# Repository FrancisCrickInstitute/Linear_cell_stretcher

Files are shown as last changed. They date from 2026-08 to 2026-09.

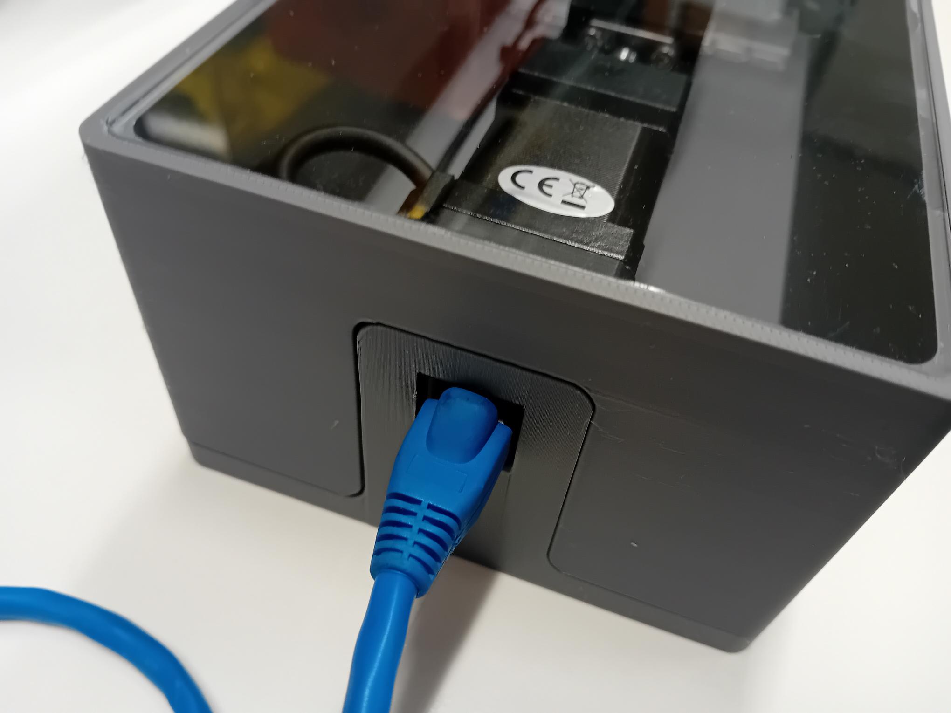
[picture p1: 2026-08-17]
Media/20260624_161759.jpg

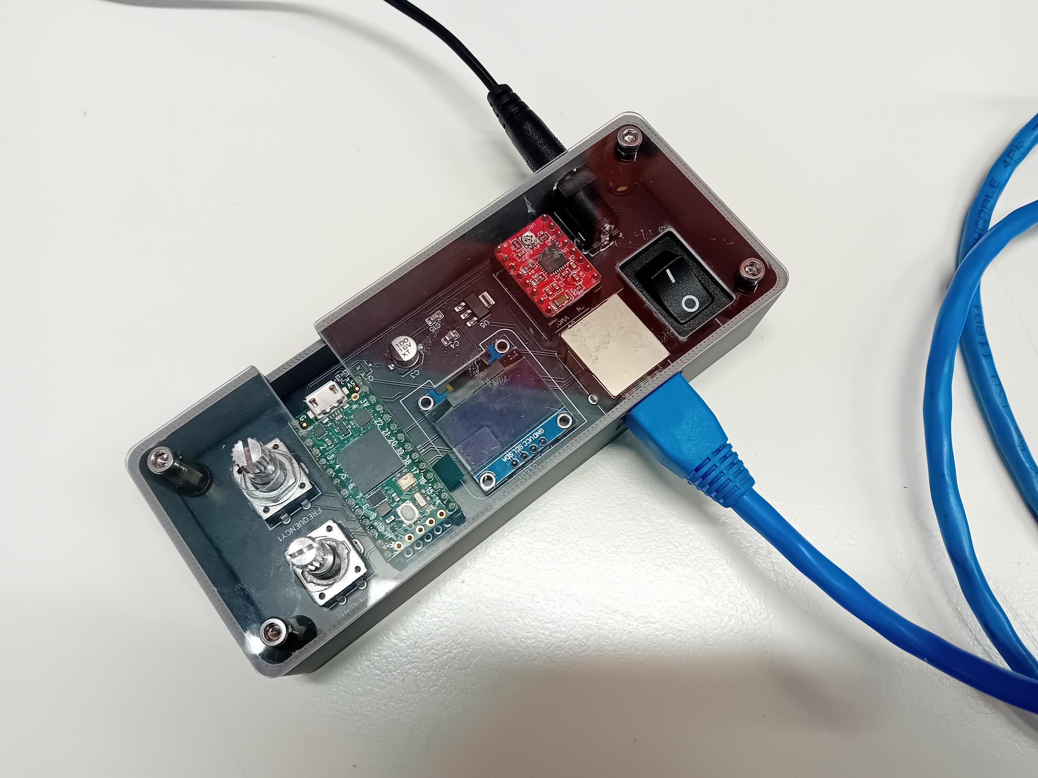
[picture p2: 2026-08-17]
Media/20260624_161749.jpg

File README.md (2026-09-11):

## Linear cell stretcher

Slide2

### Bill of Materials (BOM)

| Name | Quantity | Link |
| :--- | :---: | :--- |
| Linear stepper motor stage | 1 | [Stepper online](https://www.stepperonline.co.uk/nema-14-stepper-ball-screw-linear-actuator-1-5a-stroke-40mm-0-2nm-28-32oz-in-lead-2mm-0-0787-with-sensor-lmd14s18bab15-040.html) |
| Teensy 4.0 | 1 | [PiHut](https://thepihut.com/products/teensy-4-0-headers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) |
| Stepper motor driver | 1 | [Amazon](https://www.amazon.co.uk/dp/B07XRF8YPX?ref=fed_asin_title) |
| M2 threaded inserts | 4 | [Amazon](https://www.amazon.co.uk/dp/B0DFBVLHH7?ref=fed_asin_title&th=1) |
| M3 threaded inserts | 4 | [Amazon](https://www.amazon.co.uk/dp/B0DFBTB5LN?ref=fed_asin_title&th=1) |
| 5 mm rods (For the stretcher)| 1 | [Amazon](https://www.amazon.co.uk/dp/B0FHK1SYZM?ref=fed_asin_title&th=1) |
| 5.2 mm rods (For the mould)| 1 | [Amazon](https://www.amazon.co.uk/dp/B0DYT6DDYS?ref=fed_asin_title&th=1) |
| 12V AD/DC power adapter | 1 | [Amazon](https://www.amazon.co.uk/Adapter-100-240V-Transformer-Charger-Cameras/dp/B0FJ5NYKD2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) |
| M3 x 50 mm button screws | 2 | [Accu](https://www.accu.co.uk/socket-button-screws/8115-SSB-M3-50-A2) |
| RJ45 patch cable | 1 | [Amazon]() |
| M2 screws | 4 | [Accu]() |
| M3 screws | 10 | [Accu]() |

### Assembly instructions

- 3D print the components using more than 50% infill settings and PLA as material
- Laser cut the two-part lid cover
- Insert M2 threaded inserts on the bottom sides of the 3D printed parts: puller and the enclosure base
- Solder the Control PCB components

- Cut to the right length and solder the optical homing sensor cable and the stepper motor cable with the linear stepper connection board


- Attach the linear stepper connection board at the back of the motor with the 3D printed spacer in between removing two of the original stepper motor screws and replacing them by two 50 mm M3 screws.


- Place four M3 inserts in the enclosure base and lid holes
- Glue the big part of the lid cover on top of the 3D printed enclosure lid. The front smaller lid is not glued as it is removable to be able to access the wells with the pipette

- Change the position of the homing sensor using the front side M3 tapped holes


- Attach the 3D printed beam breaker on the carriage using two M3 screws


- Attach the 3D printed puller on top of the linear stage carriage using 4 M3 screws


- Attach the linear stage with the enclosure base (3D printed) using four M3 screws


- The 5 mm bars are held using 2 M2 screws in both the puller and the 3D printed enclosure


- Grab the optical sensor cable through the two cable guides


- Place 4 grub screws into the enclosure lid holes and place the lid on top of the enclosure base


- Upload the firmware on the Teensy 4

- Conenct the device and the control board using a RJ45 cable

- Connect the 12V, 36W power supply in the control board barrel jack connector


- Select the frequency (0.05 - 1 Hz) and stretch length (using the stretch and frequancy knobs) and mode (pressing the stretch knob) 

- Press the frequency knob to change the state of the device to active and it will start pulling, if pressed and held again it will stop at the end of the cycle

- Place the PDMS wells in the rods


#### Modes:
- Cyclic stretch
- Cyclic stretch holding for a defined period of time (specified in the firmware)
- Stretch and hold

### PDMS mould casting process

The moulds for creating the wells have been 3D printed using Formlabs clear V5 resin in a Form 4 3D printer. After IPA washing (15 min) and UV curing (60 degC for 1h on the Formlabs Form cure) they have been baked in the oven at 75 degC for 4h to ensure a completely crosslinked structure. Then 1:10 PDMS ratio has been poured and cured at 65 degC for 4h. Then the 5.2 mm rods can be removed and the PDMS wells carefully peeled off using a flat thin spatula.



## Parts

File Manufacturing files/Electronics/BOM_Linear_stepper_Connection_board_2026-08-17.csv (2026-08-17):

ID | Name | Designator | Footprint | Quantity | Manufacturer Part | Manufacturer | Supplier | Supplier Part | Price | Pins
1 | R-RJ45S08P-A002 | RJ1 | RJ45-TH_CKMTW_R-RJ45S08P-A002 | 1 | R-RJ45S08P-A002 | Ckmtw(灿科盟) | LCSC | C17179563 | 0.262 | 8
2 | HDR-F-2.54_1x4 | MOTOR | HDR-F-2.54_1X4 | 1 |  |  | LCSC | C225501 | 0.098 | 4
3 | HDR-M-2.54_1x3 | PHOTO | HDR-M-2.54_1X3 | 1 |  |  | LCSC | C180248 | 0.214 | 3

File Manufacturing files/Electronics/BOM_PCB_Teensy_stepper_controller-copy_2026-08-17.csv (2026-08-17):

ID | Name | Designator | Footprint | Quantity | Manufacturer Part | Manufacturer | Supplier | Supplier Part | Price | Pins
1 | 100uF | C3 | CAP-SMD_BD6.3-L6.6-W6.6-LS7.4-FD | 1 |  | KNSCHA(科尼盛) | LCSC | C2992593 | 0.033 | 2
2 | 10uF | C4 | C0805 | 1 | CL21A106KAYNNNE | SAMSUNG | LCSC | C15850 | 0.101 | 2
3 | 100nF | C15 | C0805 | 1 | CC0805KRX7R9BB104 | YAGEO | LCSC | C49678 | 0.023 | 2
4 | PEC11R-4015F-S0024 | FREQUENCY1,STRETCH1 | SW-TH_PEC11R-4XXXF-SXXXX | 2 | PEC11R-4015F-S0024 | BOURNS | LCSC | C143789 | 3.022 | 7
5 | DC005-2.0MM | IN1 | DC-IN-TH_DC005 | 1 | DC005-2.0MM | SOFNG | LCSC | C111567 | 0.232 | 3
6 | 0.96OLED_4P | OLED1 | 0.96OLED_4P | 1 |  |  | LCSC |  |  | 4
7 | BSS138 | Q3 | SOT-23-3_L2.9-W1.3-P1.90-LS2.4-BR | 1 | BSS138 | CJ(江苏长电/长晶) | LCSC | C78284 | 0.019 | 3
8 | 10k | R3,R4 | R0603 | 2 | 0603WAF1002T5E | UniOhm | LCSC | C25804 | 0.009 | 2
9 | Rocker switch601-10211BB | SW3 | SW-TH_601-10211BB | 1 | Rocker switch601-10211BB | BBJ | LCSC | C67849 |  | 3
10 | R-RJ45R10P-B000 | TO_STRETCHER1 | RJ45-TH_R-RJ45R10P-B000 | 1 | R-RJ45R10P-B000 | Shenzhen Cankemeng | LCSC | C386758 | 0.407 | 10
11 | TEENSY-3.2_NO_INNER_HEADERSPTH | U1 | TEENSY_TEENSY-3.2-PTH | 1 |  |  |  |  |  | 33
12 | STEPPER DRIVER POLOLU A4988 | U4 | POLOLU A4988 | 1 |  | Pololu | GoTronic |  |  | 16
13 | LD1117S50TR | U5 | SOT-223-3_L6.5-W3.4-P2.30-LS7.0-BR | 1 | LD1117S50TR | STMicroelectronics | LCSC | C134077 | 0.195 | 4

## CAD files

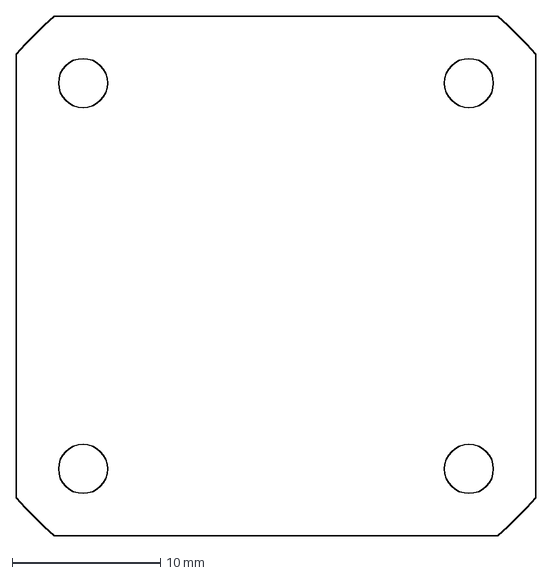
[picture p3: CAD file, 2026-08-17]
CAD files/Nema_14_PCB.dxf
35.0 x 35.0 mm

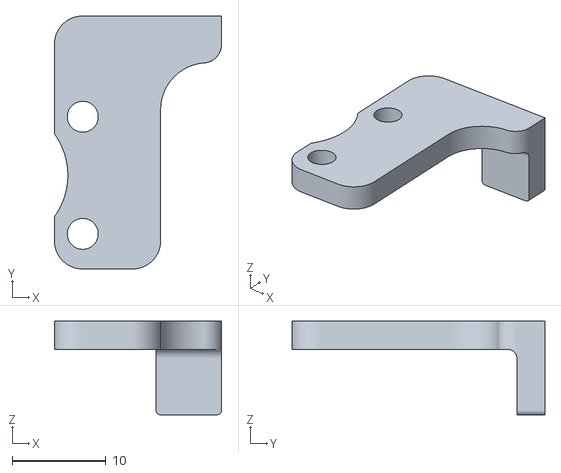
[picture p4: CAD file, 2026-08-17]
Manufacturing files/Mechanical/Beam breaker.stl
17.8 x 27.0 x 10.0

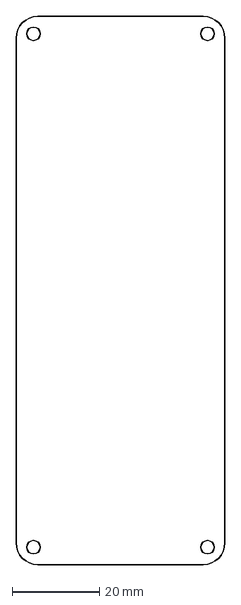
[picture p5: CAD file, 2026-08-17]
CAD files/Control_board_PCB.dxf
48.0 x 126.0 mm

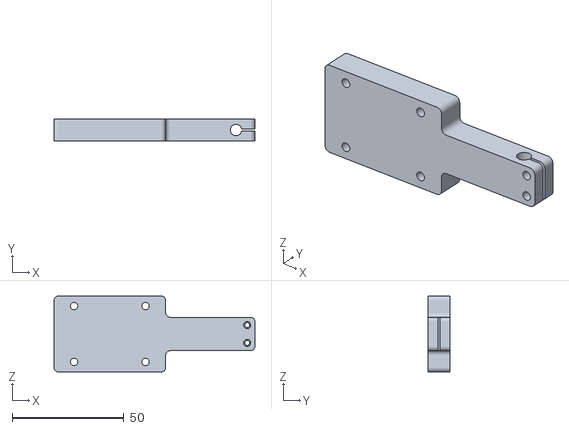
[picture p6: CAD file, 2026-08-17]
Manufacturing files/Mechanical/Puller.stl
90.0 x 10.0 x 34.0

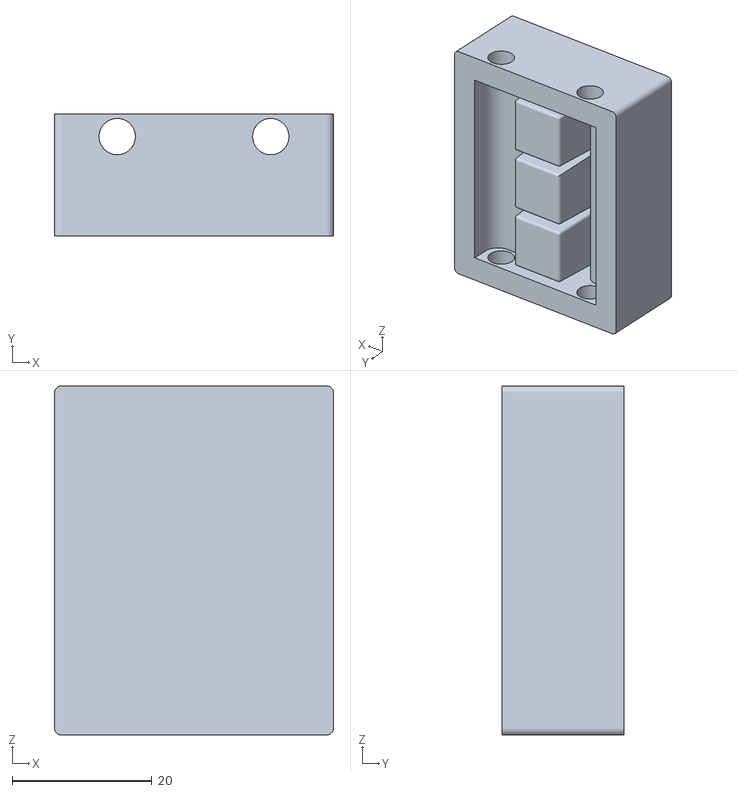
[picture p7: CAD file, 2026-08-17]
Manufacturing files/Mechanical/Mould_3 wells.stl
40.0 x 17.5 x 50.0

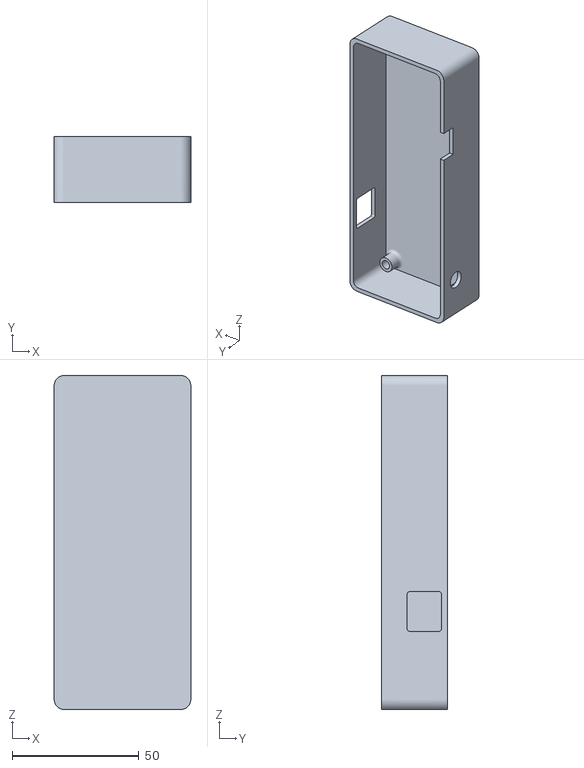
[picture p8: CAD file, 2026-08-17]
Manufacturing files/Mechanical/Control_PCB_enclosure.stl
54.0 x 26.0 x 132.0

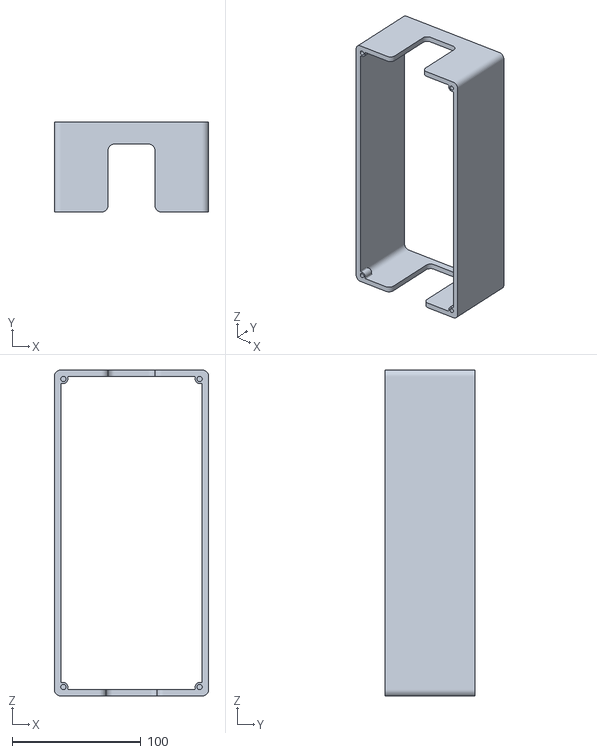
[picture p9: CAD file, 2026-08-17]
Manufacturing files/Mechanical/Eclosure lid.stl
120.0 x 70.0 x 253.5

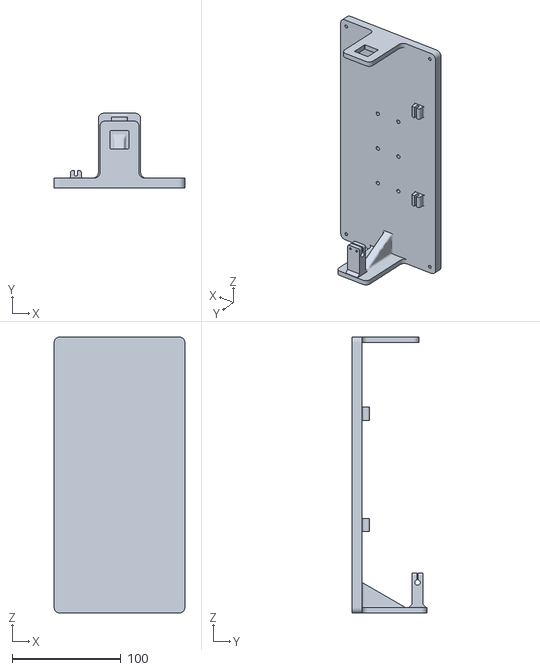
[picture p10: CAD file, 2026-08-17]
Manufacturing files/Mechanical/Enclosure base.stl
120.0 x 68.5 x 253.5

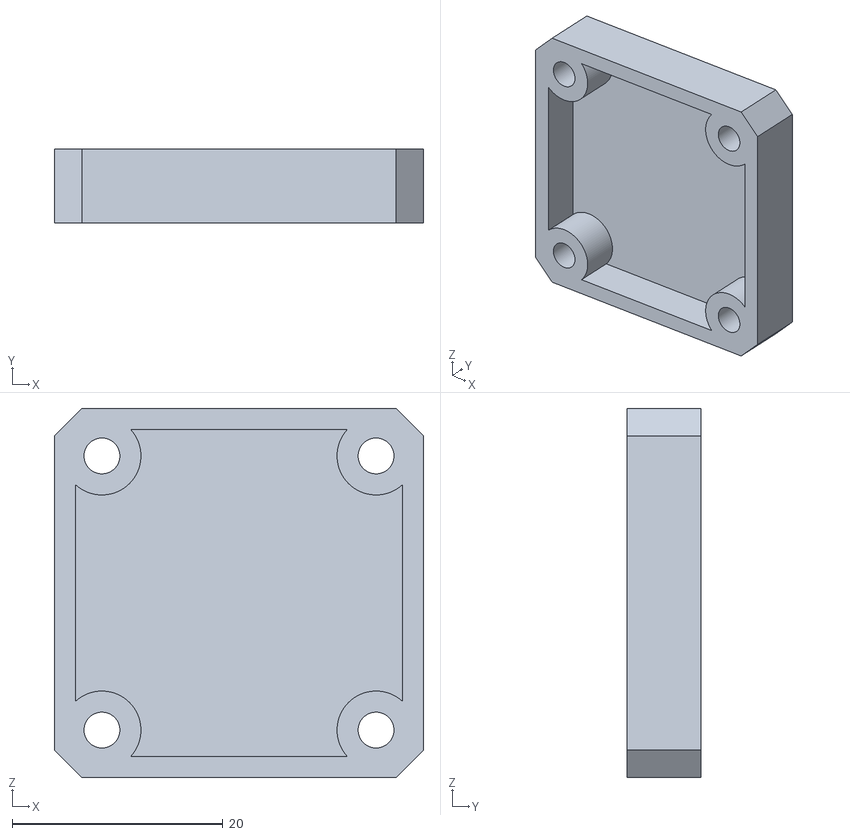
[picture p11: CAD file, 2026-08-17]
Manufacturing files/Mechanical/PCB_Spacer.stl
35.0 x 7.00 x 35.0

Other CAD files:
CAD files/03-42-914.ipt
CAD files/03-42-916.ipt
CAD files/09-28-002.ipt
CAD files/11-003.ipt
CAD files/12-004.ipt
CAD files/12-005(12-005-21).ipt
CAD files/12-005.ipt
CAD files/12-015.ipt
CAD files/12-016.ipt
CAD files/16-35-901.ipt
CAD files/16-35-902.ipt
CAD files/16-35-903.ipt
CAD files/16-35-904.ipt
CAD files/16-42-914.ipt
CAD files/21-42-903.ipt
CAD files/28-35-001.iam
CAD files/28-35-002.ipt
CAD files/28-42-903.ipt
CAD files/B35E247-0-1.5-4-STD.ipt
CAD files/Beam breaker.ipt
CAD files/Control_PCB.ipt
CAD files/Control_PCB_enclosure.ipt
CAD files/Control_PCB_enclosure_lid.ipt
CAD files/Eclosure lid.ipt
CAD files/Enclosure base.ipt
CAD files/LMD14S18BAB15-040.iam
CAD files/Linear_stretcher.iam
CAD files/Mould_3 wells.ipt
CAD files/PCB_Spacer.ipt
CAD files/PMMA_lid.ipt
CAD files/PMMA_lid_long.ipt
CAD files/Puller.ipt
CAD files/Rod.ipt
CAD files/Well.ipt

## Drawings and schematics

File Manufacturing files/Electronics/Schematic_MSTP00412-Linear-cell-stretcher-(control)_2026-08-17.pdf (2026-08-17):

## Power

## Teensy 3.2

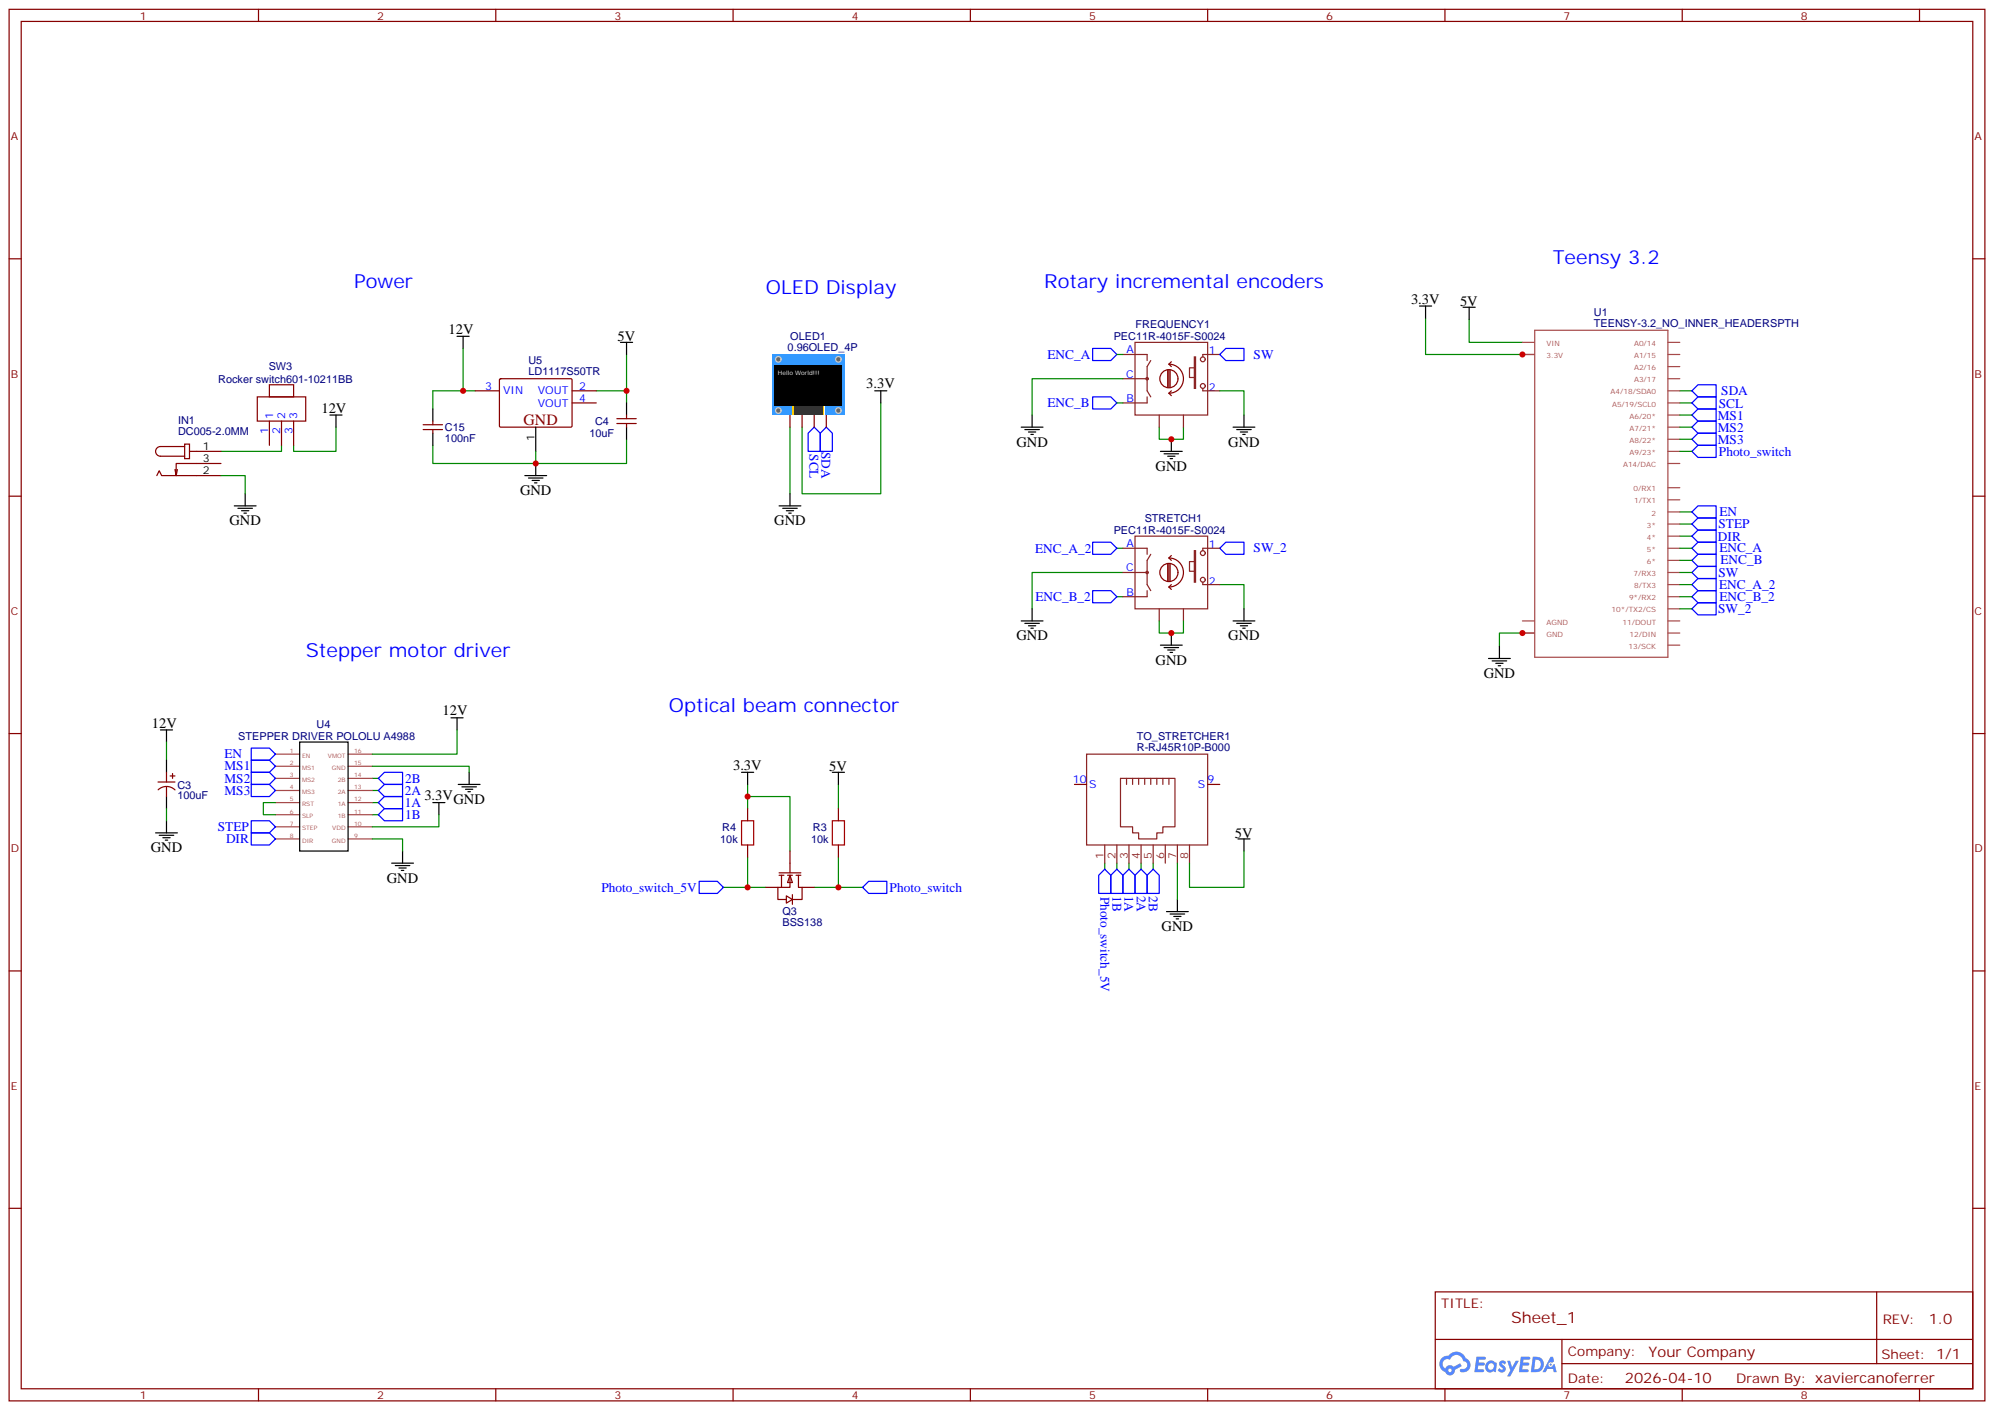
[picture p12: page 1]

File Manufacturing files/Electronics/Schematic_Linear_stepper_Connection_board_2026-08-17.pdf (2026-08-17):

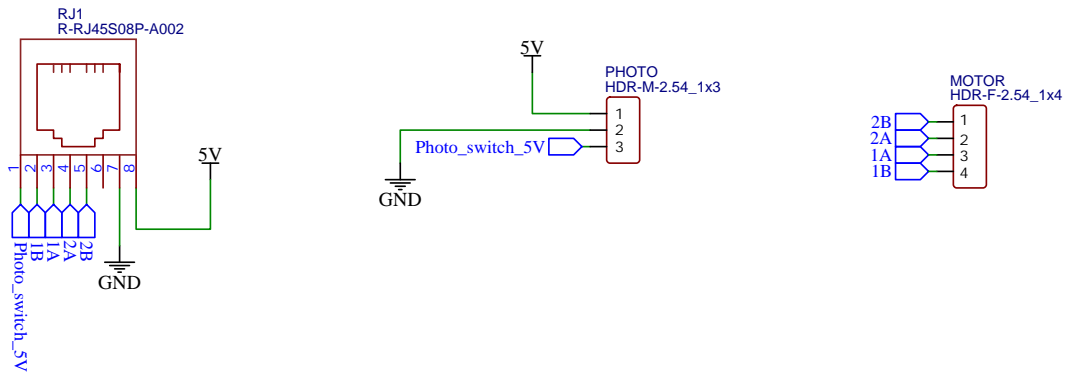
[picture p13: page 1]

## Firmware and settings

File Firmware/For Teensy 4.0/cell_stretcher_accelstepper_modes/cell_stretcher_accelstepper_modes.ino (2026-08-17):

#include <AccelStepper.h>
#include <Encoder.h>
#include <Wire.h>
#include <Adafruit_GFX.h>
#include <Adafruit_SSD1306.h>
#include <Bounce.h>

Encoder freq_knob(5, 6);
Encoder stretch_knob(8, 9);

const int encoder_SW = 7;
const int encoder_SW_2 = 10;

// Instantiate a Bounce object with a 20 millisecond debounce time
Bounce pushbutton = Bounce( encoder_SW,20 ); 
Bounce pushbutton2 = Bounce( encoder_SW_2,20 ); 

const int Enable = 2;
const int DIR = 4;
const int STEP = 3;

// AccelStepper in DRIVER mode (STEP/DIR driver such as A4988, DRV8825, etc.)
AccelStepper M1(AccelStepper::DRIVER, STEP, DIR);

const int SW1 = 23; // Photo_switch
//const int SW2 = 17;
//const int SW3 = 21;
//const int SW4 = 23;

// NOTE: TeensyStep's StepControl is no longer needed with AccelStepper.
// Movement is handled directly via M1.moveTo() + M1.run() / M1.runToPosition().

#define SCREEN_WIDTH 128 // OLED display width, in pixels
#define SCREEN_HEIGHT 64 // OLED display height, in pixels

// Declaration for an SSD1306 display connected to I2C (SDA, SCL pins)
#define OLED_RESET     -1 // Reset pin # (or -1 if sharing Arduino reset pin)

Adafruit_SSD1306 display(SCREEN_WIDTH, SCREEN_HEIGHT, &Wire, OLED_RESET);

const int MS1 = 20;
const int MS2 = 21;
const int MS3 = 22;

float um_per_step = 1.6; //400 steps/revolution
const int steps_per_mm = 100;
int steps = 0;
const int initial_pos_mm = 1;
const int initial_steps = initial_pos_mm*steps_per_mm;
const int compression_steps = 3000;

int mode = 0;

float freq = 0;
float freq_factor = 0.05;
float stretch = 0;
float T;
const float initial_stretch_length = 20;
float p_stretch;
unsigned long t = 0;
bool state = 0;
float vel;
int steps_s;
float accel;
int steps_s2;

void setup()
{
  pinMode(MS1, OUTPUT);    // set the MS1, MS2, MS3 and Enable as an outputs
  pinMode(MS2, OUTPUT);
  pinMode(MS3, OUTPUT);

  pinMode(Enable, OUTPUT);

  digitalWrite(MS1, LOW); 
  digitalWrite(MS2, LOW);
  digitalWrite(MS3, LOW);

  digitalWrite(Enable, LOW); // set the enables to LOW

  // Set the motor max speed and acceleration
  M1.setMaxSpeed(1000);      // stp/s
  M1.setAcceleration(5000);  // stp/s^2

  // TeensyStep's setInverseRotation(false) has no direct AccelStepper equivalent.
  // If the motor turns the wrong way, use:
  //   M1.setPinsInverted(true, false, false); // (directionInvert, stepInvert, enableInvert)

  pinMode(SW1, INPUT_PULLUP);
  
  pinMode(encoder_SW, INPUT_PULLUP);
  pinMode(encoder_SW_2, INPUT_PULLUP);
  
  Serial.begin(115200);

  display.begin(SSD1306_SWITCHCAPVCC, 0x3C);

  delay(1000);
  display.clearDisplay(); 

  display.setTextColor(WHITE);        // Draw white text
  display.setCursor(0, 0);
  display.setTextSize(1);
  display.println(F("HOMING"));
  display.display();
  
  Homing_routine();
  
  Serial.println("Homing completed");

  // The homing routine moves the motor manually (bit-banging STEP),
  // so AccelStepper's internal position tracking needs to be reset
  // to match the physical home position.
  M1.setCurrentPosition(0);

  //delay(1000);
  // Go to initial position
  M1.moveTo(initial_steps);
  M1.runToPosition(); // blocks until the target position is reached

  
  digitalWrite(Enable, HIGH); // Remove power from the motor to decrease heat
  
}

void loop()
{

//Serial.println(digitalRead(SW1));
  freq = abs(freq_knob.read())/4*freq_factor; // Select the frequency in Hz
  stretch = abs(stretch_knob.read())/4*0.05; // select the stretch in mm 

  //Constrained frequancy and stretch
  freq = constrain(freq, 0, 1);
  stretch = constrain(stretch, 0, 3);
  
  
  p_stretch = stretch/(initial_stretch_length)*100; // Calculate percentage of stretch, period and motor speed based on the previous user selection
  T = 1/freq; // Calculate the period

  vel = 1.5*(stretch/(T/2)); // 1.5 = 3/2 Because 1/3 of the time is used for accelerating, 1/3 is used for constant velocity, and 1/3 is used for decelerating.
  accel = vel/(T/6);
  
  t = T*1000; // Convert the period in milliseconds

  // Get steps from mm selected by the user using the stretch knob
  steps = mm_to_step(stretch); // Divided by two beacuse it is what will move each arm

  // Get steps/s from the selected velocity
  steps_s = mm_to_step(vel);

  // Get steps/s^2 from the acceleration calculated based on displacement and frequency
  steps_s2 = mm_to_step(accel);
  
  //Set the selected motor speed
  set_velocity(steps_s);

  //Set the acceleration
  set_acceleration(steps_s2);

  OLED_display(); // Display selection

  read_pushbutton();
  read_pushbutton2();

  
//  if (state == 1)
//  {
//    read_pushbutton();
//    simultaneous();  
//  }

  if (state == 1 && mode == 0)
  {
    read_pushbutton();
    cyclic();  
  }

  if (state == 1 && mode == 1)
  {
    read_pushbutton();
    cyclic_delay();  
  }
  if (state == 1 && mode == 2)
  {
    read_pushbutton();
    stretch_hold();
  };
//  if (state == 1 && mode == 3)
//  {
//    read_pushbutton();
//    x_axis();
//  };
//  if (state == 1 && mode == 4)
//  {
//    read_pushbutton();
//    y_axis();
//  };
//  if (state == 1 && mode == 5)
//  {
//    read_pushbutton();
//    compression();
//  };
}

// Function to get the steps from the mm
int mm_to_step (float mm)
{
  int steps;
  steps = mm * 100; // 100 steps per mm
  return steps;
}

// Function to get the mm from the steps
float step_to_mm (int steps)
{
  float mm;
  mm = steps * 0.01; // 0.01 mm per step
  return mm;
}

//Function to rotate the left motor CW
void TurnClockwise_M1 (int pd)
{
  digitalWrite(DIR, 0);
  digitalWrite(STEP, HIGH);
  digitalWrite(STEP, LOW);
  delayMicroseconds(pd);
}

void read_pushbutton()
{
  if (pushbutton.update())
  {
    if (pushbutton.fallingEdge())
    {
      state = !state;
    }
  }
}

void read_pushbutton2()
{
  if (pushbutton2.update())
  {
    if (pushbutton2.fallingEdge())
    {
      mode = mode +1;
      mode = constrain(mode, 0, 2);
    }
  }
}

void Homing_routine()
{
  
  while (digitalRead(SW1) == LOW)
  {
    TurnClockwise_M1 (5000);
    Serial.println(digitalRead(SW1));
  }
}

void set_velocity(int v)
{  
  // Set the motor max speed
  M1.setMaxSpeed(v);
}

void set_acceleration(int a)
{  
  // Set the motor max acceleration
  M1.setAcceleration(a);
}
void OLED_display()
{
  display.clearDisplay();
  display.setTextColor(WHITE);        // Draw white text
  display.setCursor(0, 0);
  display.setTextSize(1);
  display.println(F("Cell stretcher"));
  display.println();
  display.print(F("Frequency:"));
  display.print(freq);
  display.println(F(" Hz"));
  //display.println();
  display.print(F("Stretch:"));
  display.print(stretch);
  display.println(F(" mm"));
  //display.println();
  display.print(F("%Stretch:"));
  display.print(p_stretch);
  display.println(F(" %"));
//  display.print(F("Steps stretch:"));
//  display.println(steps);
  //display.println();
  display.print(F("Period:"));
  display.print(T);
  display.println(F(" s"));
  //display.println();
  display.print(F("State:"));
  //display.print(state);
  if (state == 0){display.println(F("Inactive"));}
  if (state == 1){display.println(F("Active"));}
  display.print(F("Mode:"));
  //display.println(F("Simult"));
  if (mode == 0){display.println(F("Cyclic"));}
  if (mode == 1){display.println(F("Cyclic_delay"));}
  if (mode == 2){display.println(F("SH_T"));}
//  if (mode == 3){display.println(F("X axis"));}
//  if (mode == 4){display.println(F("Y axis"));}
//  if (mode == 5){display.println(F("Compress"));}
//  display.print(mode);
  display.display();
}

void cyclic()
{
   digitalWrite(Enable, LOW); // Enable the motor again
    
    // Set the target and move to it (blocking until reached)
    M1.moveTo(initial_steps+steps);
    M1.runToPosition();

    digitalWrite(Enable, HIGH); // Remove power from the motor to decrease heat

    digitalWrite(Enable, LOW); // Enable the motor again

    // Come back to the origin
    M1.moveTo(initial_steps);
    M1.runToPosition();

    digitalWrite(Enable, HIGH); // Remove power from the motor to decrease heat  
}


void cyclic_delay()
{
   digitalWrite(Enable, LOW); // Enable the motor again
    
    // Set the target and move to it (blocking until reached)
    M1.moveTo(initial_steps+steps);
    M1.runToPosition();

    digitalWrite(Enable, HIGH); // Remove power from the motor to decrease heat

    delay(2000);//delay(7200000); // Hold for 2h

    digitalWrite(Enable, LOW); // Enable the motor again

    // Come back to the origin
    M1.moveTo(initial_steps);
    M1.runToPosition();

    digitalWrite(Enable, HIGH); // Remove power from the motor to decrease heat  
}

void stretch_hold()
{
   digitalWrite(Enable, LOW); // Enable the motor again
    
    // Set the target and move to it (blocking until reached)
    M1.moveTo(initial_steps+steps);
    M1.runToPosition();

    digitalWrite(Enable, HIGH); // Remove power from the motor to decrease heat

    while(state == 1)
    {
      read_pushbutton();
      if (state == 0)
      {
        digitalWrite(Enable, LOW); // Enable the motor again

        // Come back to the origin
        M1.moveTo(initial_steps);
        M1.runToPosition();

        digitalWrite(Enable, HIGH); // Remove power from the motor to decrease heat  
      }
    }

}
